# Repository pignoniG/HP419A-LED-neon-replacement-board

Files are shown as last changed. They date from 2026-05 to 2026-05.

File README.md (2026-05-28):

# HP419A-LED-neon-replacement-board
HP419A LED neon Replacement board (based on Mr.Carson's lab design)
This board replaces the neons in a HP419A, as well as the oscillator circuit, should be powered by the + - 13v (battery + battery - lines )

You will have to adjust led current based on your LED, with mine os5rpm57e1a (https://www.tme.eu/it/details/os5rpm57e1a-mn/diodi-led-tht-rotondi/optosupply/) i settled on powering them with 2.5K ohm in series.

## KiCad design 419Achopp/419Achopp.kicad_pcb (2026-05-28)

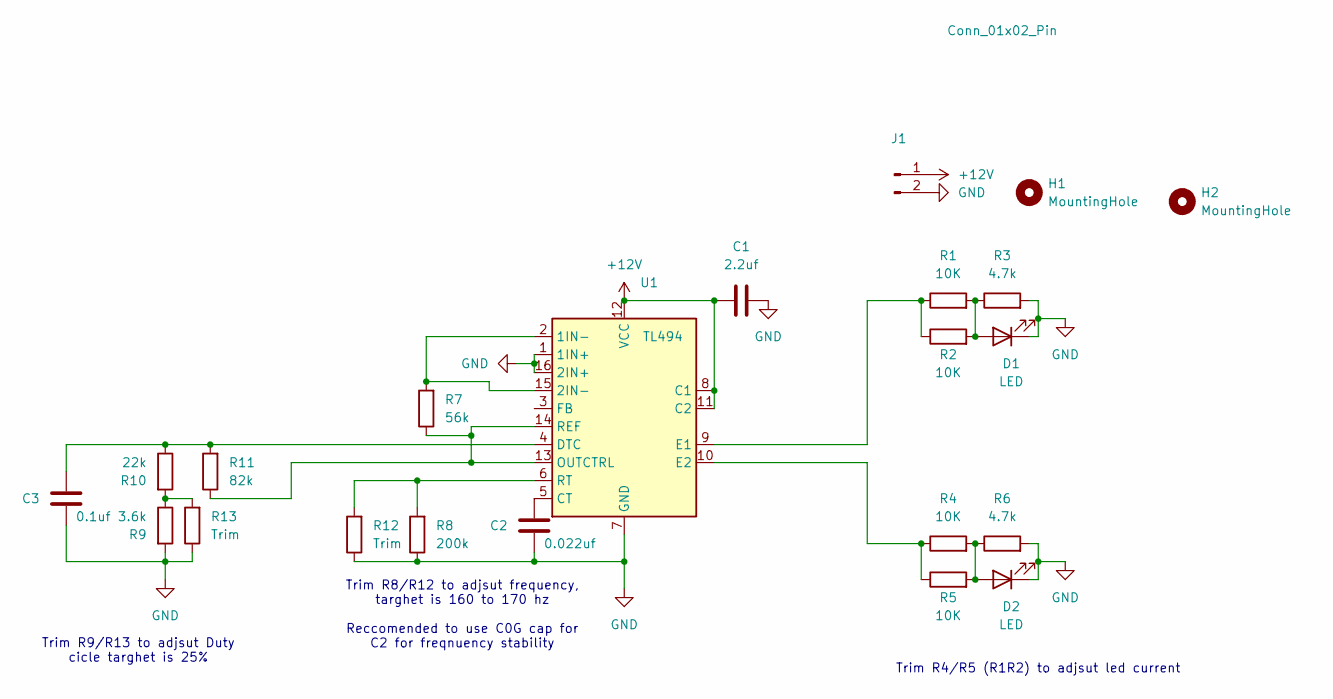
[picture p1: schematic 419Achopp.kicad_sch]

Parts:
C1: 2.2uf; R_1206_3216Metric
C2: 0.022uf; R_1206_3216Metric
C3: 0.1uf; R_1206_3216Metric
D1, D2: LED; LED_D5.0mm_Clear
H1, H2: MountingHole; MountingHole_3.7mm
J1: Conn_01x02_Pin; PinHeader_2x01_P2.00mm_Vertical
R1, R2, R4, R5: 10K; R_1206_3216Metric
R3, R6: 4.7k; R_1206_3216Metric
R7: 56k; C_0805_2012Metric
R8: 200k; C_0805_2012Metric
R9: 3.6k; C_0805_2012Metric
R10: 22k; C_0805_2012Metric
R11: 82k; C_0805_2012Metric
R12, R13: Trim; C_0805_2012Metric
U1: TL494; SOIC-16_3.9x9.9mm_P1.27mm

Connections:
+12V: C1.1, J1.1, U1.8 (C1), U1.11 (C2), U1.12 (VCC)
GND: C1.2, C2.1, C3.1, D1.1 (K), D2.1 (K), J1.2, R3.2, R6.2, R8.1, R9.2, R12.1, R13.1, U1.1 (1IN+), U1.7 (GND), U1.16 (2IN+)
unnamed: D1.2 (A), R1.2, R2.2, R3.1
unnamed: D2.2 (A), R4.2, R5.2, R6.1
unnamed: R9.1, R10.2, R13.2
unnamed: R7.2, U1.2 (1IN-), U1.15 (2IN-)
unnamed: C2.2, U1.5 (CT)
unnamed: C3.2, R10.1, R11.2, U1.4 (DTC)
unnamed: R1.1, R2.1, U1.9 (E1)
unnamed: R4.1, R5.1, U1.10 (E2)
unnamed: R7.1, R11.1, U1.13 (OUTCTRL), U1.14 (REF)
unnamed: R8.2, R12.2, U1.6 (RT)

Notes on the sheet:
Trim R8/R12 to adjsut frequency, targhet is 160 to 170 hz Reccomended to use C0G cap for C2 for freqnuency stability
Trim R4/R5 (R1R2) to adjsut led current
Trim R9/R13 to adjsut Duty cicle targhet is 25%

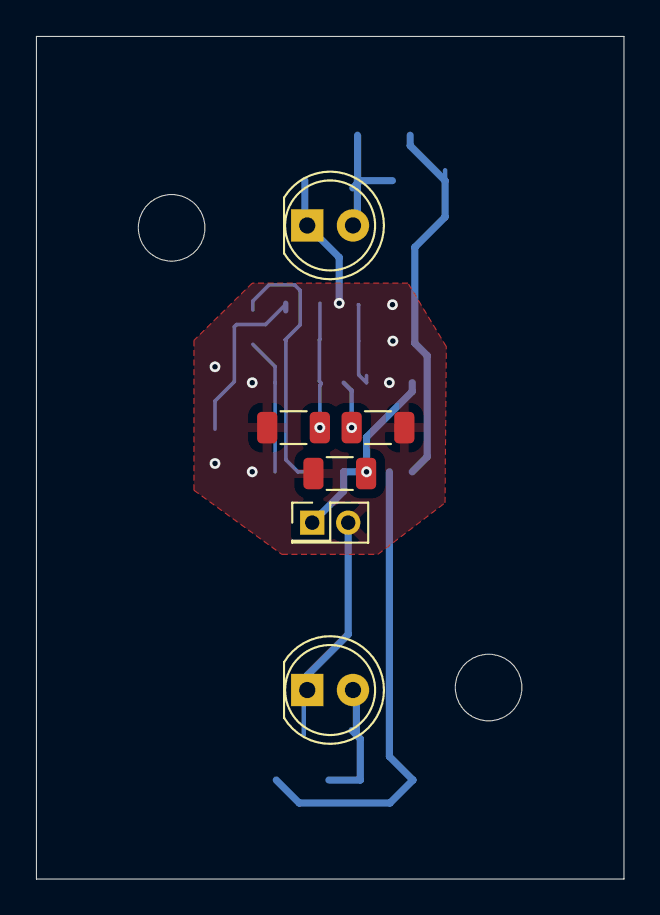
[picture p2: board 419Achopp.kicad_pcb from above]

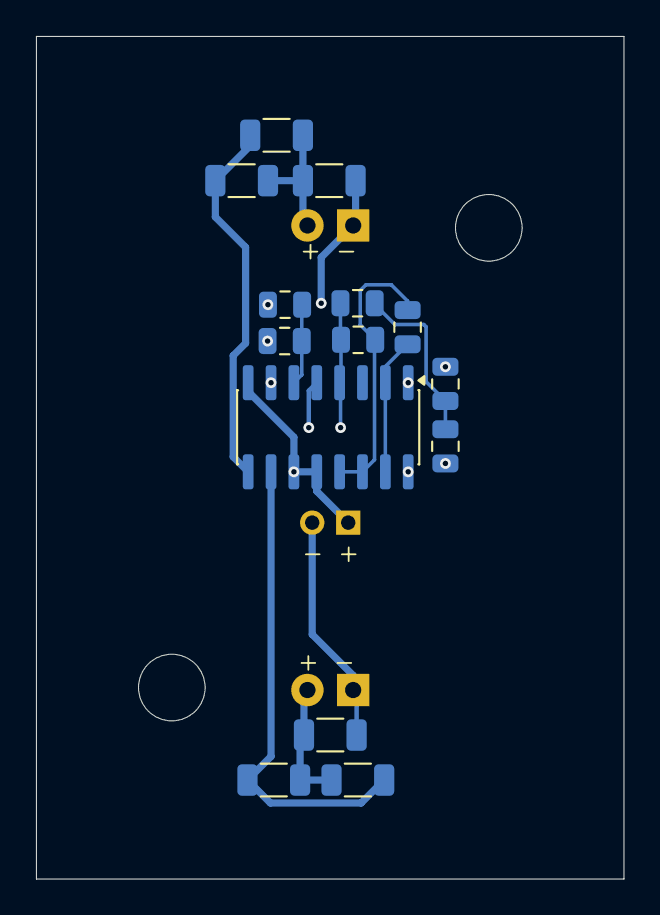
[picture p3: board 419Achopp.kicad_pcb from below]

Board: 2 copper layers, 32.6 x 46.8 mm, 22 parts (14 on the bottom side), 12 nets.

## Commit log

2026-05-28 Add files via upload
    init
    [419Achopp-B_Cu.gbr, 419Achopp-B_Mask.gbr, 419Achopp-B_Paste.gbr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]
2026-05-28 Update README with LED current and power info
    Added details about LED current adjustment and power requirements.
